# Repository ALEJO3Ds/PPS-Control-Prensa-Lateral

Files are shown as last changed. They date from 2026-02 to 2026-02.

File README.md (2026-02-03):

<h1 align="center">
  Control Mecatrónico de Prensa Lateral en Paletizadora Industrial
</h1>

<p align="center">
  <b>Práctica Profesional Supervisada – Ingeniería Mecatrónica</b><br>
  <b>Universidad Nacional de Lomas de Zamora – Facultad de Ingeniería</b>
</p>

---

## 📑 Índice
1. [Introducción](#-introducción)
2. [Objetivo](#-objetivo)
3. [Sistema intervenido](#-sistema-intervenido)
4. [Solución implementada](#-solución-implementada)
   - [Modos FULL / LIMITADO](#-modos-full--limitado)
   - [PLC – Señales y lógica](#-plc--señales-y-lógica)
   - [HMI – Selección de modo](#-hmi--selección-de-modo)
   - [Sensor IFM MR0120 – Montaje y conexión](#-sensor-ifm-mr0120--montaje-y-conexión)
   - [Consideración neumática](#-consideración-neumática)
5. [Análisis mecánico](#-análisis-mecánico)
6. [Estructura del repositorio](#-estructura-del-repositorio)
7. [Cómo abrir y utilizar los proyectos](#-cómo-abrir-y-utilizar-los-proyectos)
8. [Archivos incluidos](#-archivos-incluidos)
9. [Autor](#-autor)

---

## 📌 Introducción

Este repositorio documenta el desarrollo de una **Práctica Profesional Supervisada (PPS)** realizada sobre un equipo industrial real: una **paletizadora automática** equipada con una **prensa lateral neumática**.

La mejora consistió en incorporar un **modo de prensado limitado** configurable desde HMI mediante un **sensor magnético ON/OFF (IFM MR0120)**, manteniendo la **secuencia** y **temporizaciones originales** del ciclo.

<p align="center">
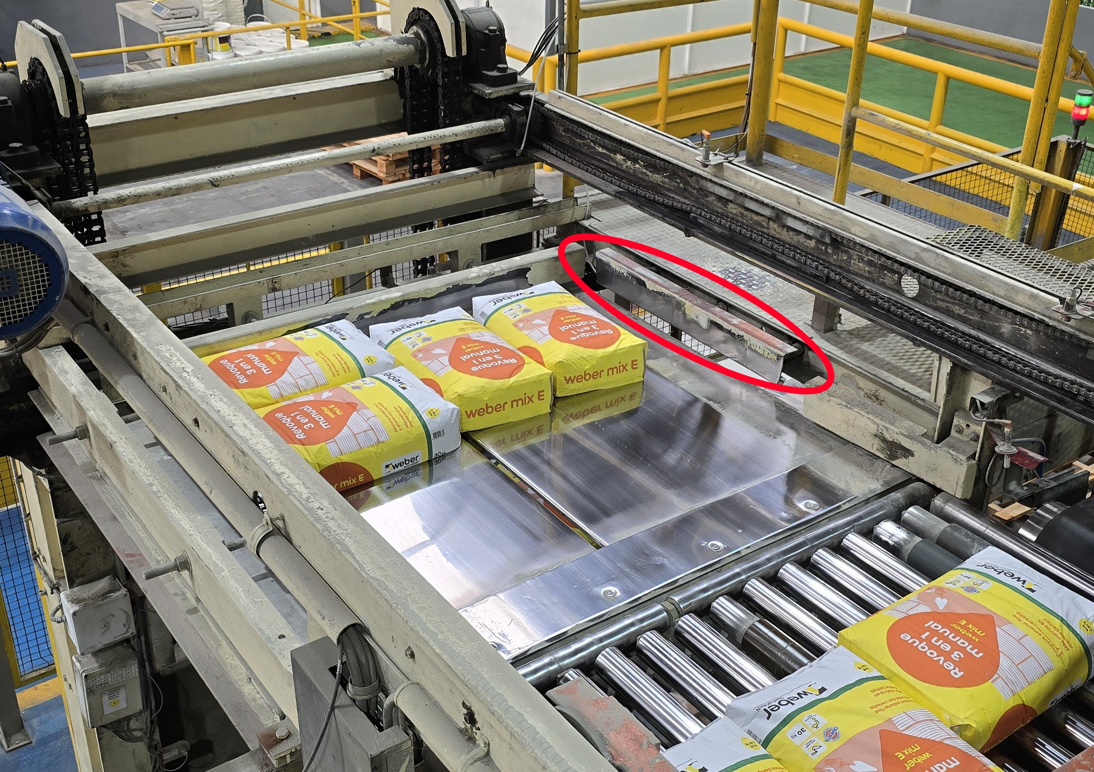
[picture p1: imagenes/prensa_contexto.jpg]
Prensa en paletizadora
  <br>
  <em>Prensa lateral neumática integrada en la paletizadora industrial</em>
</p>

---

## 🎯 Objetivo

Implementé una mejora de control para **limitar el recorrido del cilindro neumático** según necesidad operativa, sin modificar:

- la secuencia automática existente,
- las temporizaciones originales del ciclo,
- el comportamiento manual ya validado.

La solución permite detener el avance del cilindro en una posición intermedia definida por sensor, **manteniendo presión durante el tiempo original de prensado**.

---

## 🏭 Sistema intervenido

- **PLC:** Omron CJ2M-CPU34  
- **HMI:** Omron NS5  
- **Software PLC:** CX-Programmer  
- **Software HMI:** CX-Designer  
- **Cilindro neumático:** Micro 0.049.260.300 (doble efecto, con imán, carrera 300 mm)  
- **Electroválvula:** 5/3 centro cerrado  
- **Sensor agregado:** IFM MR0120 (magnético ON/OFF)

<p align="center">
  <b>Conjunto mecánico de la prensa lateral</b><br>
</p>

<table align="center">
  <tr>
    <td align="center">
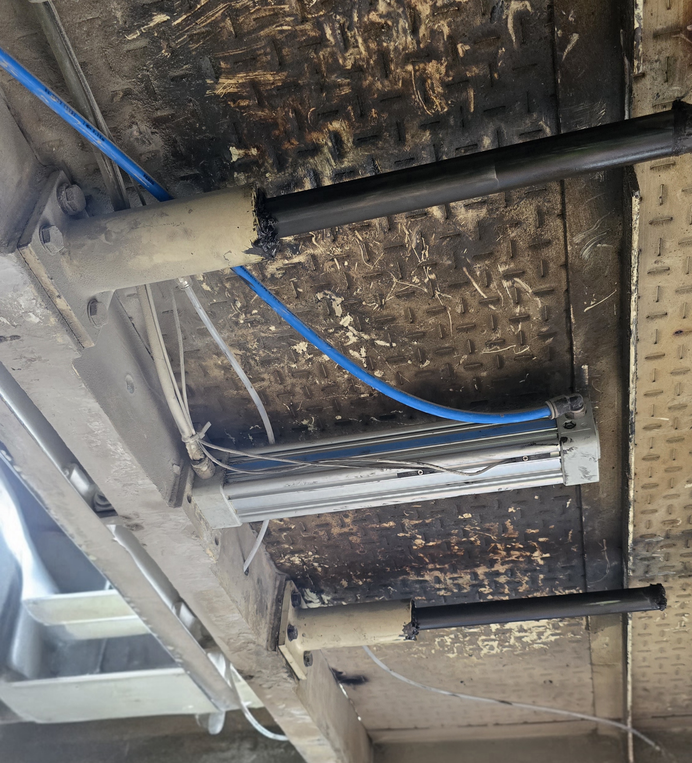
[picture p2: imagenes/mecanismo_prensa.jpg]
Implementación real de la prensa lateral
      <br>
      <em>Implementación real en paletizadora</em>
    </td>
    <td align="center">
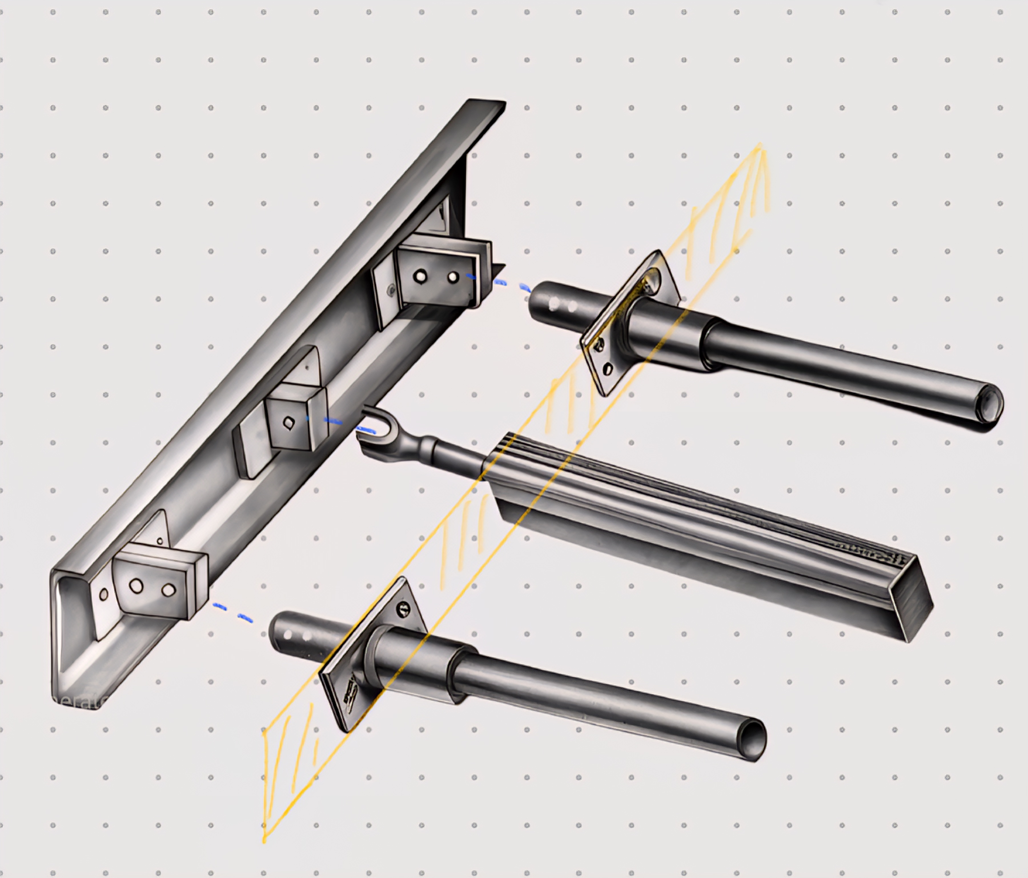
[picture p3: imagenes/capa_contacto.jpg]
Croquis del mecanismo de prensado
      <br>
      <em>Croquis / esquema mecánico</em>
    </td>
  </tr>
</table>

---

## ⚙️ Solución implementada

### 🔹 Modos FULL / LIMITADO

**Modo FULL**
- Comportamiento idéntico al original.
- El cilindro avanza a carrera completa.
- El sensor es ignorado por lógica.

**Modo LIMITADO**
- El avance se detiene cuando el sensor detecta el imán del pistón.
- Se conserva el tiempo de prensado del ciclo.
- El retroceso ocurre por la lógica global existente, sin agregar pasos nuevos.

---

### 🧠 PLC – Señales y lógica

**Entrada digital (sensor):**
- `S_PRENSA_LIMIT` → **CIO 3.14**

**Bit de modo (desde HMI):**
- `PRENSA_MODO_LIMITADO` → **CIO 610.09**
  - `0` = FULL (recorrido completo)
  - `1` = LIMITADO (recorrido limitado por sensor)

**Bit interno (bloqueo):**
- `BLOQUEO_PRENSA_LIMIT` → **W500.00**

**Cálculo del bloqueo:**
- `BLOQUEO_PRENSA_LIMIT = PRENSA_MODO_LIMITADO AND S_PRENSA_LIMIT`

**Acción sobre el avance (Y12):**
- Se agregó `NOT BLOQUEO_PRENSA_LIMIT` en los rungs que energizan el avance.
- En FULL, la lógica queda equivalente al programa original.
- En LIMITADO, al activarse el sensor se impide continuar el avance.

<p align="center">
  Rungs principales (avance/retorno)<br>
  <em>Rungs principales asociados a avance (Y12) y retroceso (Y34) de la prensa lateral en modo automático</em>
</p>

**Retroceso (Y34):**
- Se mantuvo el criterio del ciclo existente, evitando dobles mandos y conservando la secuencia validada.

---

### 🖥️ HMI – Selección de modo

La pantalla modificada fue **0011 – Programa**.  
Los Programas 1 y 2 escriben en **DM200** (selección de receta/ciclo), por lo que el modo FULL/LIMITADO se definió como **configuración global** independiente del programa activo.

Se agregaron dos botones con indicación por lámpara:

- **Prensa FULL:** escribe `0` en `HOST3:00610.09`
- **Prensa LIMITADA:** escribe `1` en `HOST3:00610.09`

<p align="center">
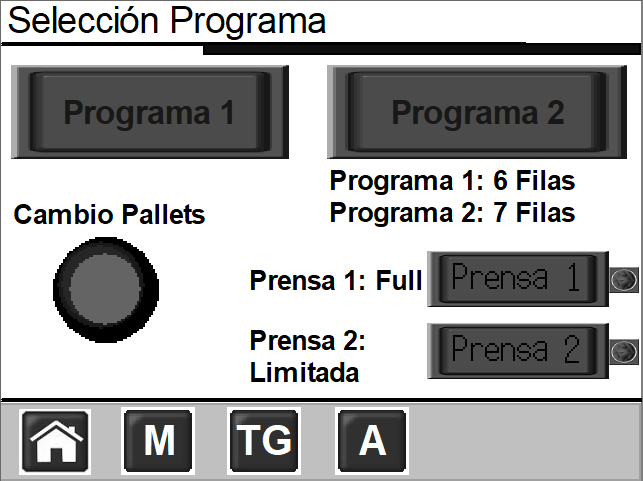
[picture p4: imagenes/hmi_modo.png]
HMI - Selección FULL/LIMITADO
  <br>
  <em>Pantalla HMI con selección de modo FULL / LIMITADO para la prensa lateral</em>
</p>

---

### 🔌 Sensor IFM MR0120 – Montaje y conexión

El sensor IFM MR0120 se monta sobre el cuerpo del cilindro y detecta el imán del pistón en una posición intermedia definida en la puesta a punto.

<p align="center">
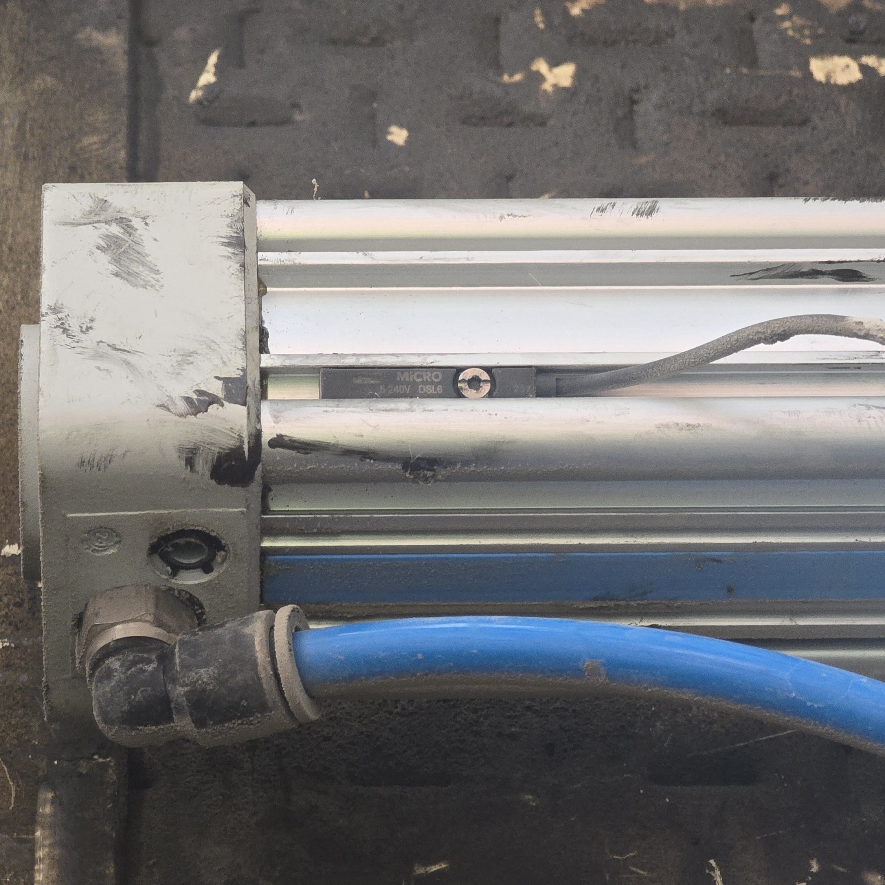
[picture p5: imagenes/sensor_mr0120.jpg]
Sensor montado en cilindro
  <br>
  <em>Sensor IFM MR0120 instalado sobre el cilindro neumático (detección magnética ON/OFF)</em>
</p>

**Conexión eléctrica (lógica PLC):**
- El sensor se cableó a la **entrada digital CIO 3.14** (`S_PRENSA_LIMIT`).

**Conexión física (dónde va el cable):**
- **PLC:** Omron CJ2M-CPU34  
- **Módulo de entradas:** **CJ1W-ID211 (DC Input Unit)**  
- **Ubicación:** Bastidor principal – **Slot 03**  
- **Borne:** **Entrada digital Nº14** del módulo (asociada a **CIO 3.14**)

> Nota: en Omron, el banco **CIO 3.xx** corresponde al módulo cuyo número de unidad/slot es **03** (16 entradas → 3.00 a 3.15).  
> Por eso **3.14** refiere a la entrada 14 de ese módulo.

**Recomendaciones de instalación:**
- Ajustar la posición del sensor según el recorrido máximo deseado.
- Verificar repetibilidad de la señal antes de habilitar el modo LIMITADO.
- Asegurar fijación mecánica firme para evitar desplazamientos por vibración.

---

### ⚠️ Consideración neumática

Se recomienda instalar una **válvula estranguladora antirretorno** para regular la velocidad del cilindro durante el avance.

**Motivo:**
- Evitar que el avance sea tan rápido que supere el punto del sensor antes de ser leído por el PLC.
- Mejorar confiabilidad de detección sin afectar el prensado.

**Ajuste recomendado:**
- Evitar estrangular en exceso (riesgo de no alcanzar el prensado a tiempo).
- Evitar estrangular de menos (riesgo de sobrepaso del punto de detección).

---

## 🧮 Análisis mecánico

Se calculó la fuerza de avance del cilindro a 6,5 bar y se verificó el conjunto mediante simulación estática (tensiones y desplazamientos).  
El análisis permitió concluir que la estructura trabaja con margen de seguridad y que el fenómeno de sobreprensado se relaciona principalmente con el recorrido impuesto y la compresibilidad del producto.

<p align="center">
  <b>Análisis por elementos finitos (FEA)</b><br>
  <em>Condiciones de contorno y resultado de deformación del conjunto bajo carga</em>
</p>

<table align="center">
  <tr>
    <td align="center">
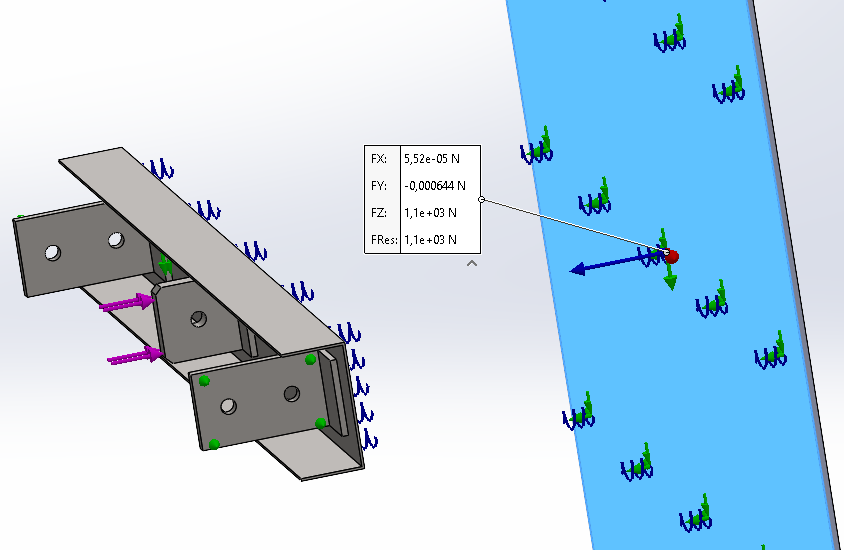
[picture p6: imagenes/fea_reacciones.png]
Configuración de cargas y reacciones (FEA)
      <br>
      <em>Configuración de cargas y reacciones</em>
    </td>
    <td align="center">
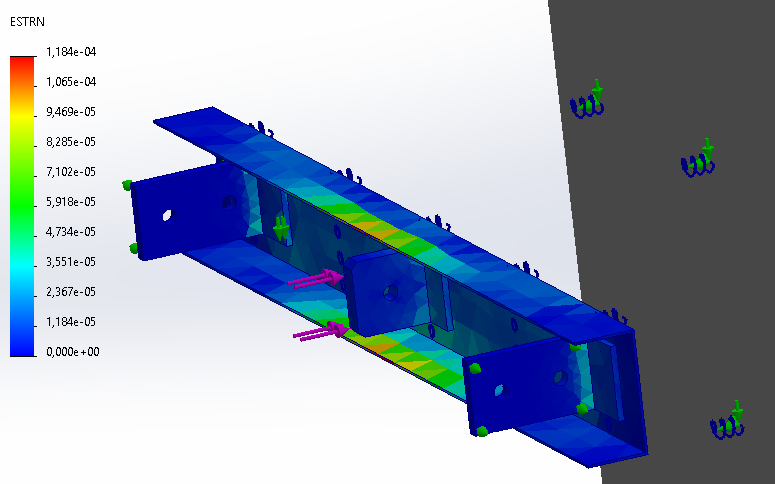
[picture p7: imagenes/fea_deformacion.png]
Resultado de deformación (FEA)
      <br>
      <em>Resultado de deformación – criterio comparativo</em>
    </td>
  </tr>
</table>

---

## 📁 Estructura del repositorio

```text
anexos/      → Documentación complementaria (PDFs)
docs/        → Informe final (PPS)
hmi/         → Proyecto HMI (.IPP) + recursos
imagenes/    → Imágenes utilizadas en este README
mecanica/    → Modelos CAD y estudios de simulación
plc/         → Proyecto PLC (.cxp) + backups y archivos asociados
```

---

## 🧰 Cómo abrir y utilizar los proyectos

### PLC (Omron CJ2M – CX-Programmer)
1. Abrí **CX-Programmer**.
2. Ir a **File → Open…** y seleccioná el archivo del proyecto:
   - `plc/PLC_Paletizadora.cxp`
3. (Opcional) Si necesitás ver el hardware configurado:
   - **PLC → I/O Table and Unit Setup** (o “Tabla de E/S” según versión).
4. Para revisar la lógica modificada:
   - Buscar las señales/símbolos:
     - `S_PRENSA_LIMIT` (CIO 3.14)
     - `PRENSA_MODO_LIMITADO` (CIO 610.09)
     - `BLOQUEO_PRENSA_LIMIT` (W500.00)
   - Ver rungs de:
     - `Y12` (EV. SALE PRENSA LATERAL)
     - `Y34` (EV. ENTRA PRENSA LATERAL)
5. Si se realiza prueba en banco/planta:
   - Conectar al PLC (USB/Serial/Ethernet según configuración del equipo).
   - **Online → Work Online**.
   - Monitorear el bit `BLOQUEO_PRENSA_LIMIT` y la entrada `CIO 3.14` al accionar el cilindro.

> ⚠️ Importante: este repositorio documenta una mejora sobre un equipo industrial real. Cualquier puesta en marcha debe respetar permisos, procedimientos internos y condiciones de seguridad del área.

---

### HMI (Omron NS5 – CX-Designer)
1. Abrí **CX-Designer**.
2. Ir a **File → Open…** y seleccioná:
   - `hmi/Pantalla_paletizadora_ver3.IPP`
3. Navegar a la pantalla modificada:
   - **Pantalla 0011 – Programa**
4. Verificar los objetos agregados:
   - Botón **Prensa FULL** → escribe `0` en `HOST3:00610.09`
   - Botón **Prensa LIMITADA** → escribe `1` en `HOST3:00610.09`
   - Lámparas asociadas al estado del bit `610.09`

---

### Sensor IFM MR0120 (montaje y conexión resumida)
- **Conexión lógica PLC:** `CIO 3.14` (`S_PRENSA_LIMIT`)
- **Conexión física (según tabla E/S):**
  - **Módulo:** `CJ1W-ID211` (DC Input Unit)
  - **Bastidor principal – Slot 03**
  - **Borne:** **Entrada digital Nº14** del módulo

> 🔧 Recomendación: ajustar una **válvula estranguladora antirretorno** para controlar la velocidad de avance del cilindro y asegurar detección confiable del sensor sin afectar el prensado.

---

## 📦 Archivos incluidos

### PLC
- `plc/PLC_Paletizadora.cxp` → Proyecto principal de PLC (Omron CX-Programmer).
- `plc/PLC_Paletizadora.bak` → Backup del proyecto.
- `plc/PLC_Paletizadora.opt` → Archivo de opciones/configuración del proyecto.
- `plc/Simbolos.pdf` → Listado de símbolos del programa PLC.
- `plc/Backup 17112025/` → Carpeta con respaldo histórico del proyecto previo a las modificaciones:
  - `PLC_Paletizadora.cxp`
  - `PLC_Paletizadora.bak`
  - `PLC_Paletizadora.cxt`
  - `PLC_Paletizadora.opt`

### HMI
- `hmi/Pantalla_paletizadora_ver3.IPP` → Proyecto HMI (Omron CX-Designer).
- `hmi/Pantalla_paletizadora_ver3/` → Carpeta asociada al proyecto HMI.
- `hmi/*.jpg` → Imágenes y recursos gráficos utilizados en la interfaz (logos, fondos, etc.).

### Mecánica
- `mecanica/Prensa.SLDASM` → Ensamble principal del conjunto de la prensa lateral.
- `mecanica/Placa.SLDPRT` → Placa estructural de la prensa.
- `mecanica/Horquilla.SLDPRT` → Horquilla del mecanismo.
- `mecanica/Orejetas.SLDPRT` → Orejetas de fijación.
- `mecanica/Prensa-EST_2_Presion_bolsas_cemento.SL3` → Estudio estático (SolidWorks Simulation).
- `mecanica/Prensa-Análisis estático 2.SL3` → Análisis estático complementario.

### Documentación
- `docs/PPS_SALTO.pdf` → Informe final de la Práctica Profesional Supervisada.
- `anexos/Funcionam-Paletizadora-Preliminar.pdf` → Descripción funcional preliminar del equipo.
- `anexos/PLC_Paletizadora_2025_General.pdf` → Documentación general del programa PLC.
- `anexos/PLC_Paletizadora_2025_Manuales.pdf` → Manuales y referencias del sistema.
- `anexos/PLC_Paletizadora_2025_Salidas_auto.pdf` → Salidas automáticas del PLC.

### Imágenes
- `imagenes/*` → Imágenes utilizadas en este README (fotografías, croquis, capturas y resultados FEA).

### Otros
- `.gitignore` → Configuración de exclusión de archivos para Git.
- `README.md` → Documentación principal del repositorio.
---

## 👤 Autor

<p align="center">
  <b>Alejo Daniel Salto</b><br>
  Ingeniería Mecatrónica – Universidad Nacional de Lomas de Zamora (FI-UNLZ)
</p>

<p align="center">
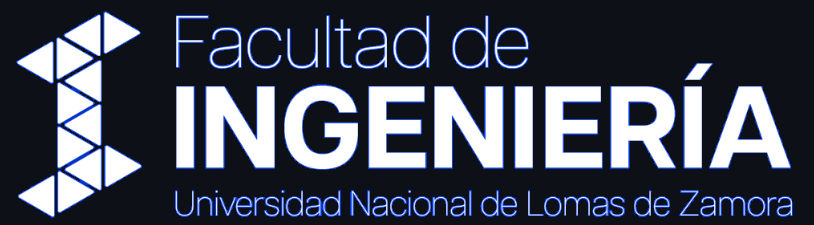
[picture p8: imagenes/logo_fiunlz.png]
Logo FiUNLZ
  
</p>

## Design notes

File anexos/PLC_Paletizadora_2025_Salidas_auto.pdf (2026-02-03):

CEMI Automatización | RDC

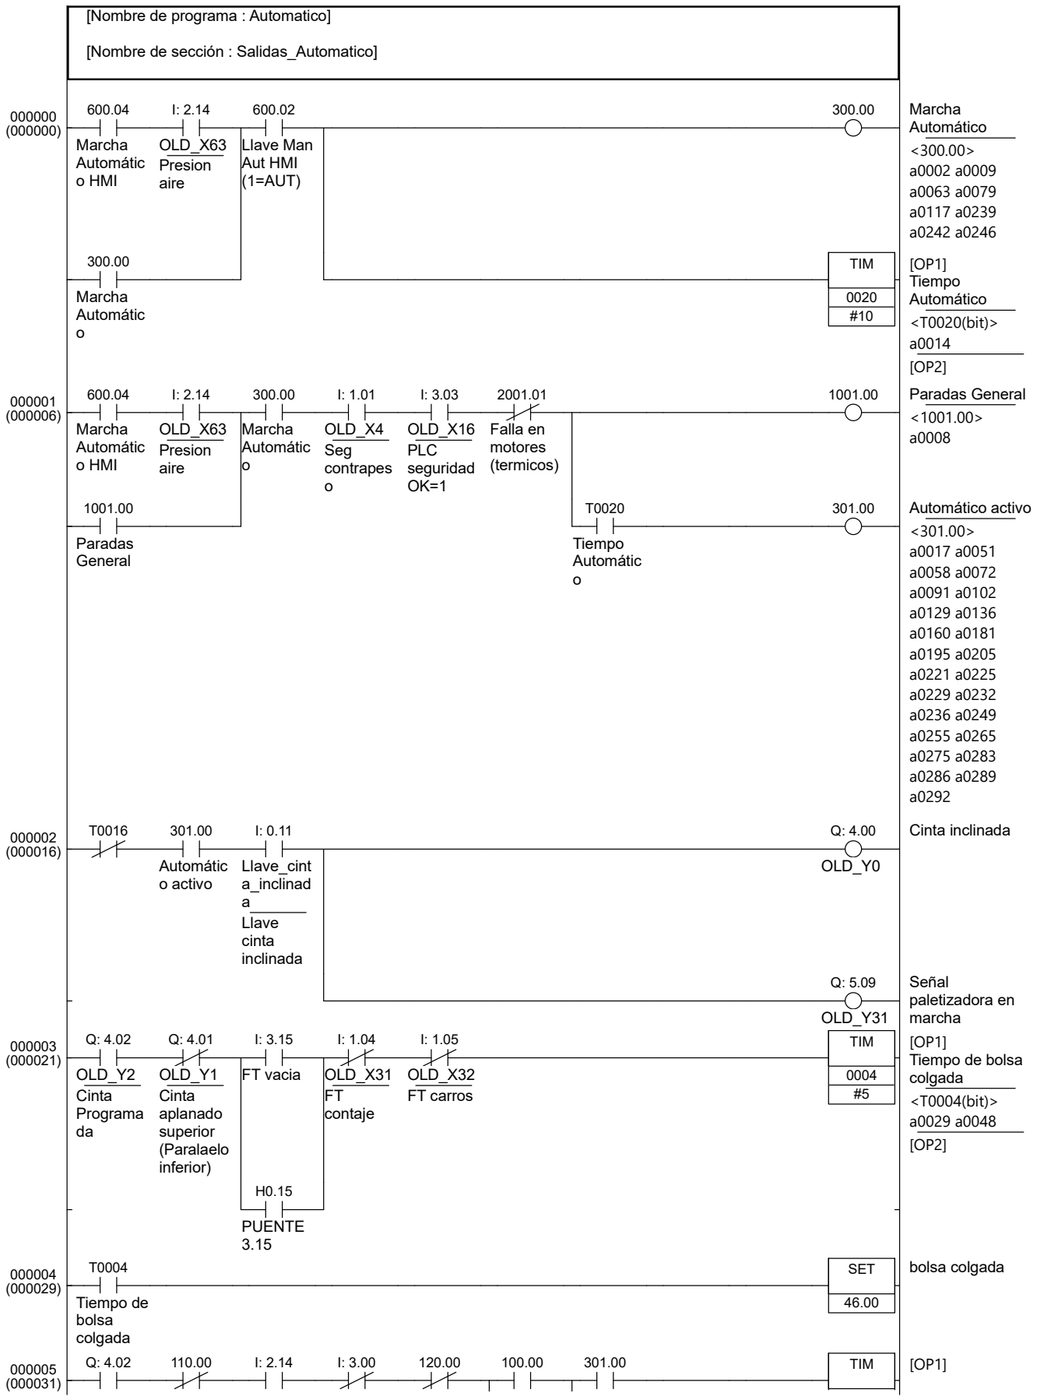
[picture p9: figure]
[Nombre de programa : Automatico]; [Nombre de sección : Salidas_Automatico]; Marcha Automátic o HMI; OLD_X63 Presion aire; Llave Man Aut HMI (1=AUT); Marcha; Automático <300.00> a0002 a0009 a0063 a0079 a0117 a0239 a0242 a0246; Marcha Automátic o; TIM; [OP1] Tiempo Automático <T0020(bit)> a0014 [OP2]; OLD_X4 Seg contrapes o; OLD_X16 PLC seguridad OK=1; Falla en motores (termicos); Paradas General; Tiempo Automátic o; Automático activo; Automátic o activo; Llave_cint a_inclinad a Llave cinta inclinada; OLD_Y0; Cinta inclinada; OLD_Y31; Señal paletizadora en marcha; OLD_Y2 Cinta Programa da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

17/11/2025 | 1 / 9 | PLC_Paletizadora.cxp

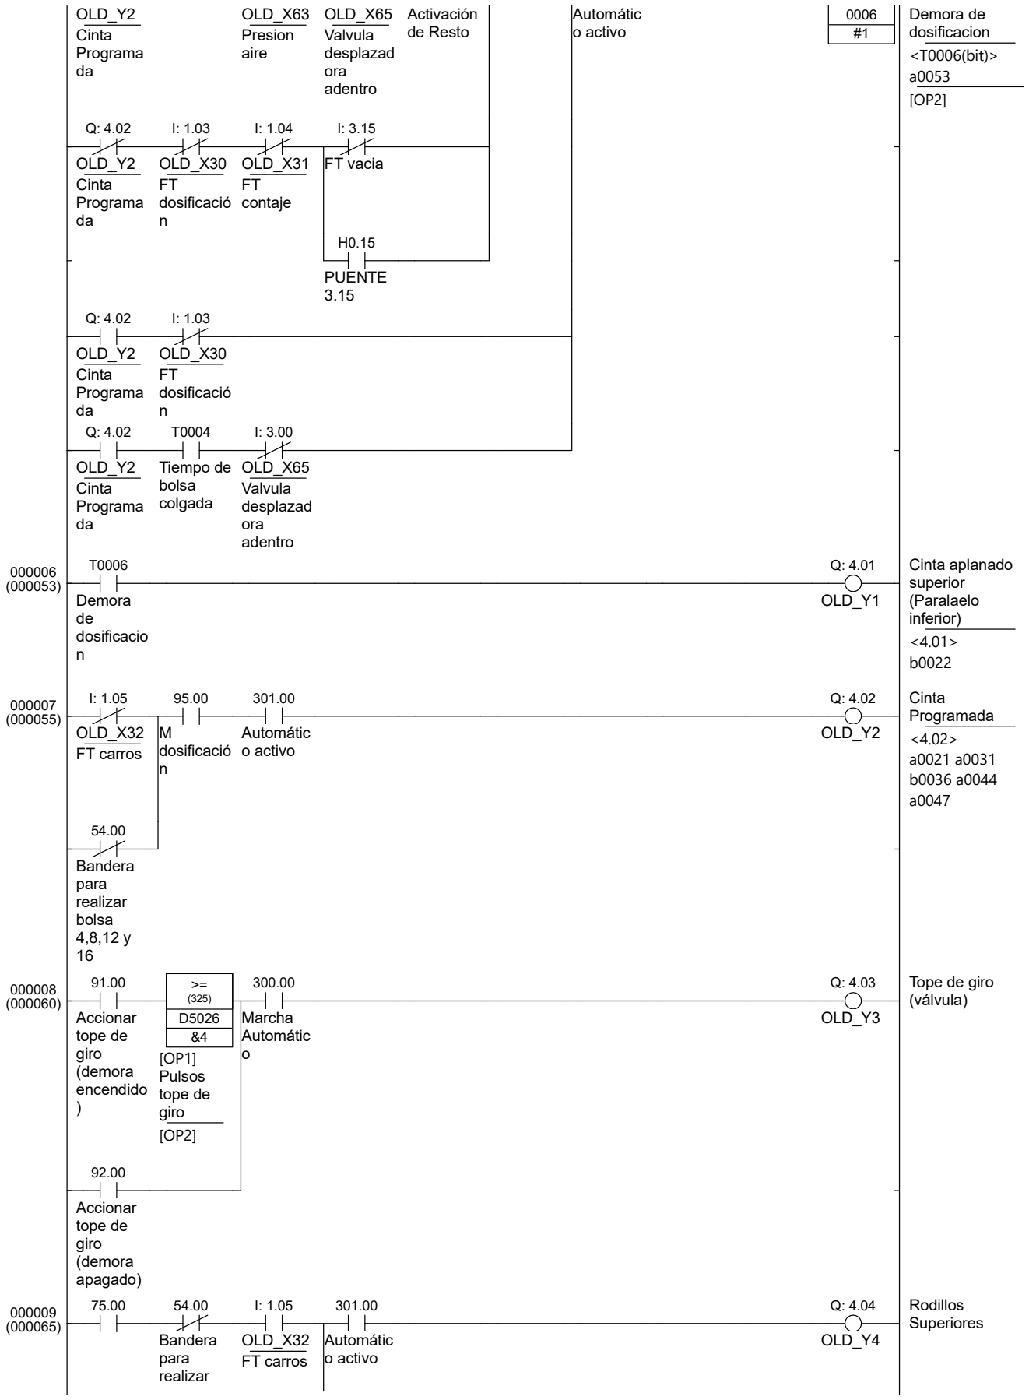
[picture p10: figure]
OLD_Y2 Cinta Programa da; OLD_X63 Presion aire; OLD_X65 Valvula desplazad ora adentro; Activación de Resto; Automátic o activo; Demora de dosificacion <T0006(bit)> a0053 [OP2]; OLD_X30 FT dosificació n; OLD_X31 FT contaje; FT vacia; PUENTE 3.15; Tiempo de bolsa colgada; Demora de dosificacio n; OLD_Y1; Cinta aplanado superior (Paralaelo inferior) <4.01> b0022; OLD_X32 FT carros; M dosificació n; OLD_Y2; Cinta Programada <4.02> a0021 a0031 b0036 a0044 a0047; Bandera para realizar bolsa 4,8,12 y 16; Accionar tope de giro (demora encendido ); >= (325) D5026 &4 [OP1] Pulsos tope de giro [OP2]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

17/11/2025 | 2 / 9 | PLC_Paletizadora.cxp

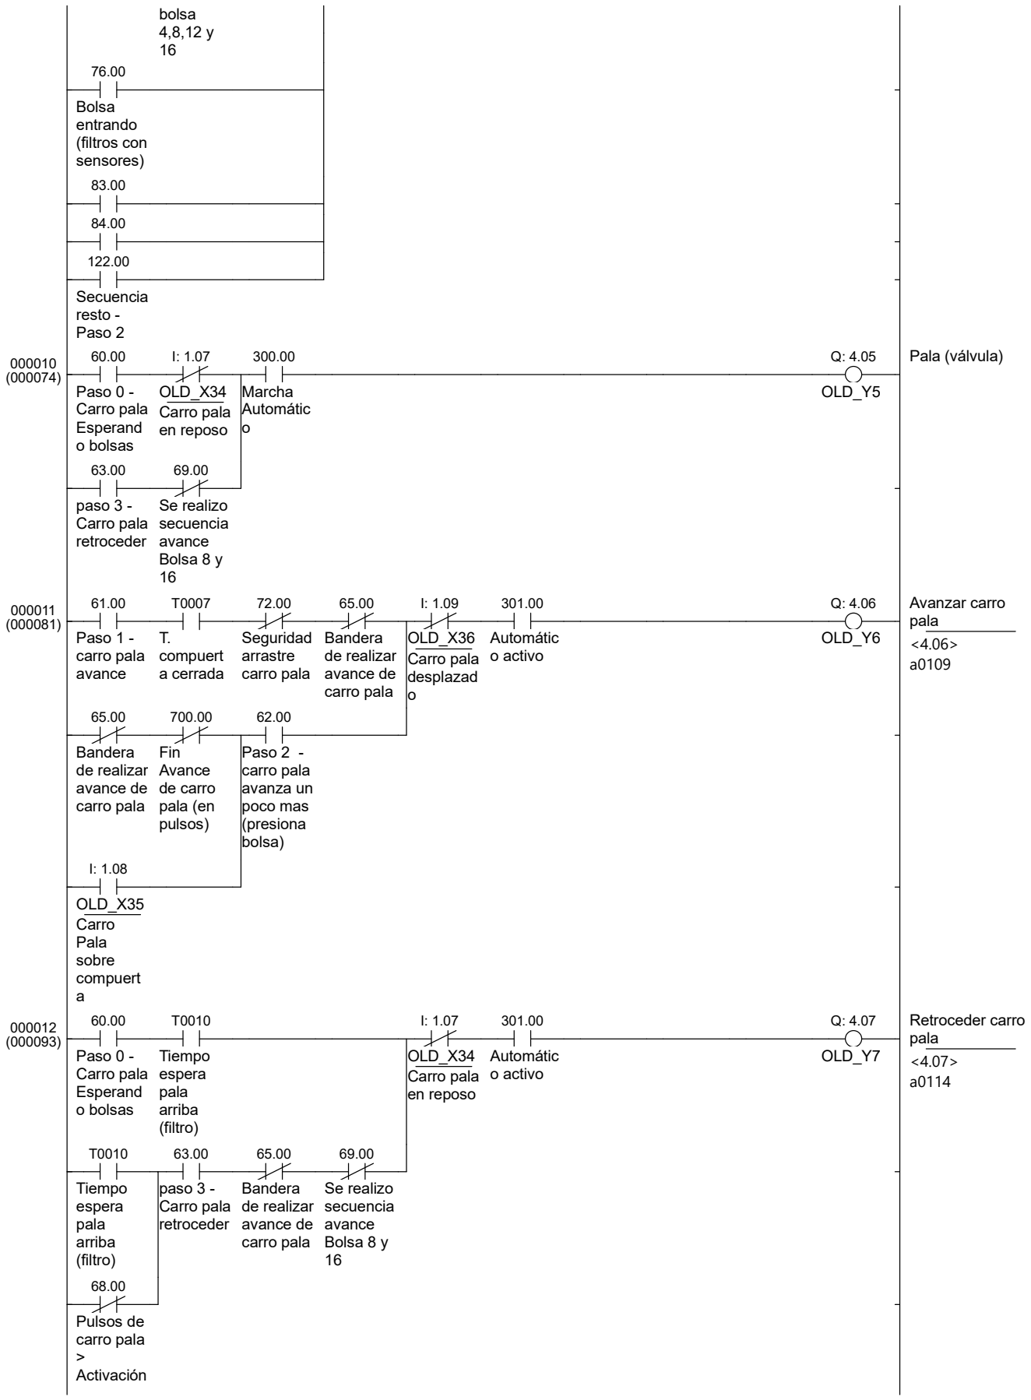
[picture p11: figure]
bolsa 4,8,12 y 16; Bolsa entrando (filtros con sensores); Secuencia resto - Paso 2; Paso 0 - Carro pala Esperand o bolsas; OLD_X34 Carro pala en reposo; Marcha Automátic o; OLD_Y5; Pala (válvula); paso 3 - Carro pala retroceder; Se realizo secuencia avance Bolsa 8 y 16; Paso 1 - carro pala avance; T. compuert a cerrada; Seguridad arrastre carro pala; Bandera de realizar avance de carro pala; OLD_X36 Carro pala desplazad o; Automátic o activo; OLD_Y6; Avanzar carro pala <4.06> a0109; Fin Avance de carro pala (en pulsos); Paso 2 - carro pala avanza un poco mas (presiona bolsa)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

17/11/2025 | 3 / 9 | PLC_Paletizadora.cxp

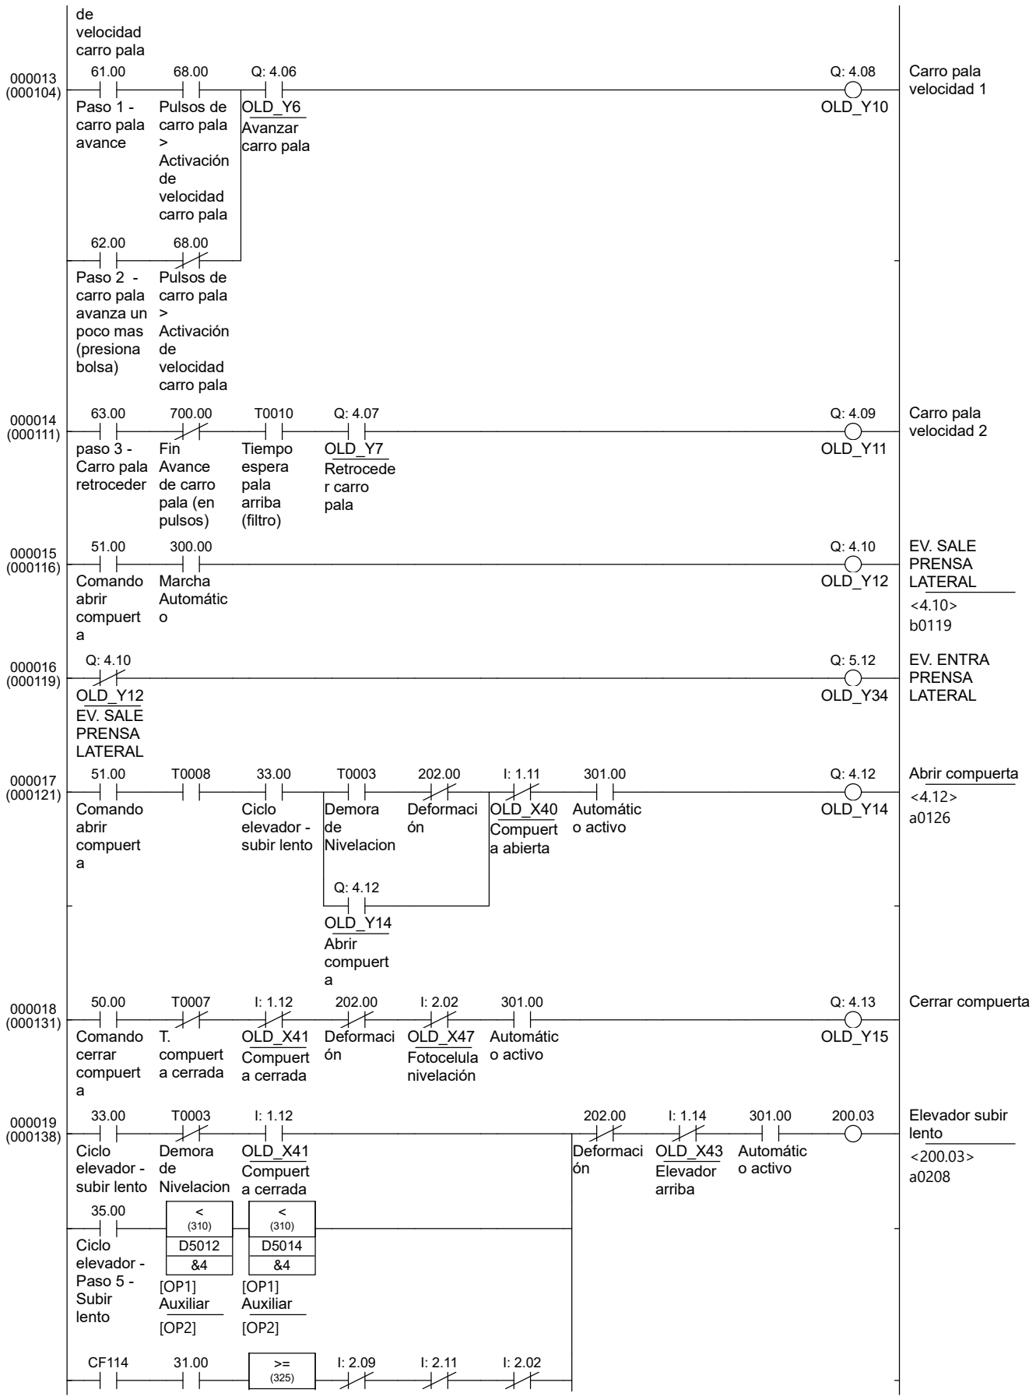
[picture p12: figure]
de velocidad carro pala; Paso 1 - carro pala avance; Pulsos de carro pala > Activación de velocidad carro pala; OLD_Y6 Avanzar carro pala; OLD_Y10; Carro pala velocidad 1; Paso 2 - carro pala avanza un poco mas (presiona bolsa); paso 3 - Carro pala retroceder; Fin Avance de carro pala (en pulsos); Tiempo espera pala arriba (filtro); OLD_Y7 Retrocede r carro pala; OLD_Y11; Carro pala velocidad 2; Comando abrir compuert a; Marcha Automátic o; OLD_Y12; EV. SALE PRENSA LATERAL <4.10> b0119; OLD_Y12 EV. SALE PRENSA LATERAL; OLD_Y34; EV. ENTRA PRENSA LATERAL; Ciclo elevador - subir lento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

17/11/2025 | 4 / 9 | PLC_Paletizadora.cxp

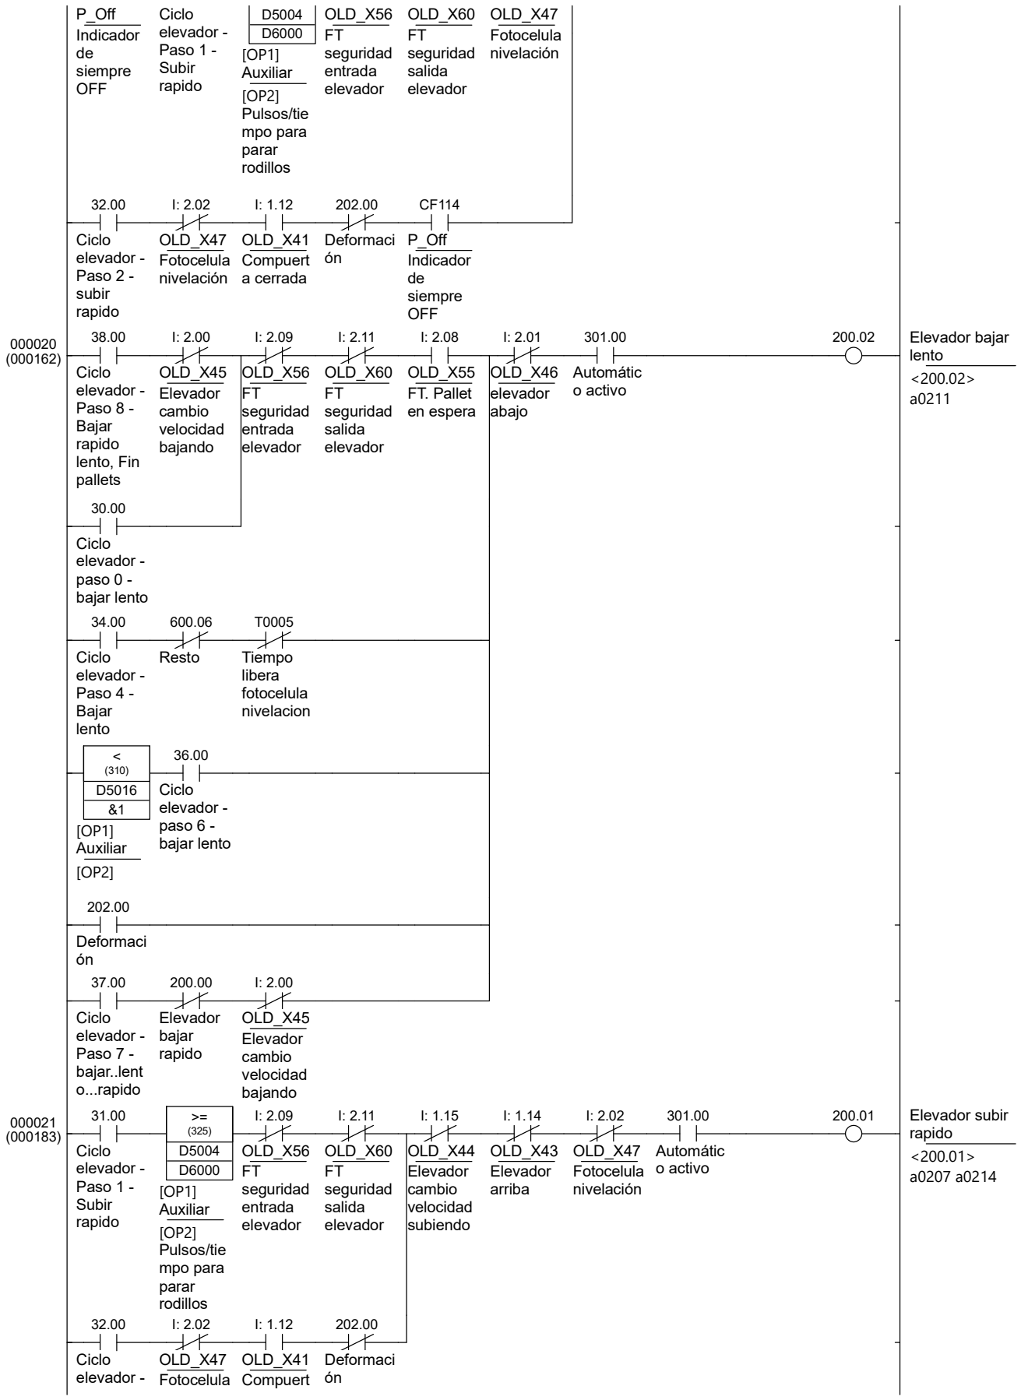
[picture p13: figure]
P_Off Indicador de siempre OFF; Ciclo elevador - Paso 1 - Subir rapido; D5004 D6000 [OP1] Auxiliar [OP2] Pulsos/tie mpo para parar rodillos; OLD_X56 FT seguridad entrada elevador; OLD_X60 FT seguridad salida elevador; OLD_X47 Fotocelula nivelación; Ciclo elevador - Paso 2 - subir rapido; OLD_X41 Compuert a cerrada; Deformaci ón; Ciclo elevador - Paso 8 - Bajar rapido lento, Fin pallets; OLD_X45 Elevador cambio velocidad bajando; OLD_X55 FT. Pallet en espera; OLD_X46 elevador abajo; Automátic o activo; Elevador bajar; lento <200.02> a0211; Ciclo elevador - paso 0 - bajar lento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

17/11/2025 | 5 / 9 | PLC_Paletizadora.cxp

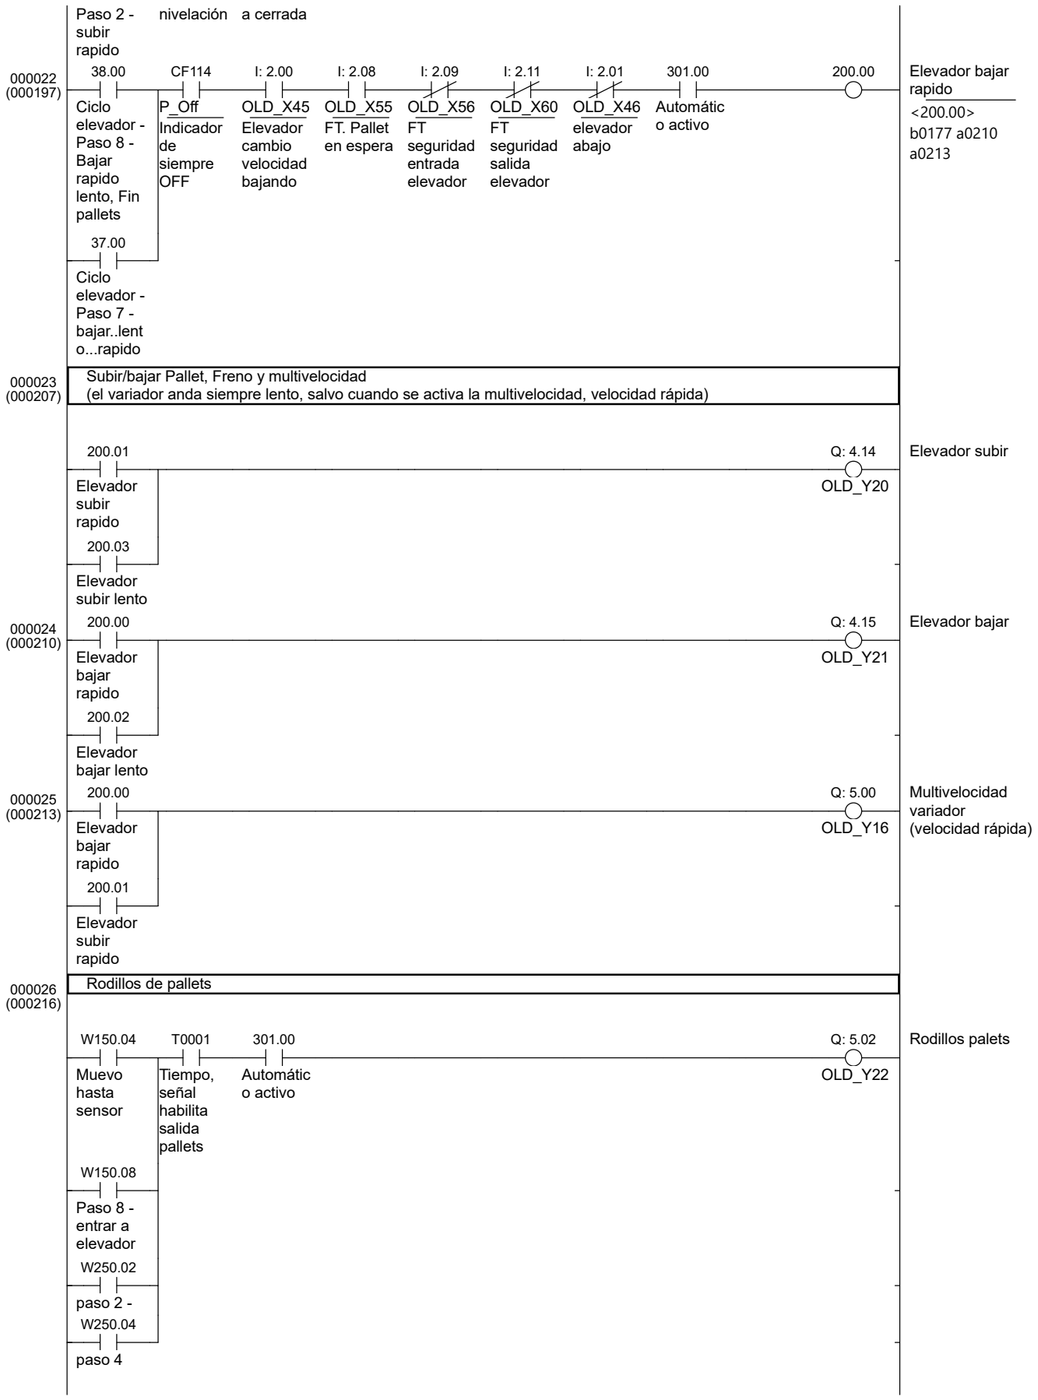
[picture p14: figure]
Paso 2 - subir rapido; nivelación a cerrada; Ciclo elevador - Paso 8 - Bajar rapido lento, Fin pallets; P_Off Indicador de siempre OFF; OLD_X45 Elevador cambio velocidad bajando; OLD_X55 FT. Pallet en espera; OLD_X56 FT seguridad entrada elevador; OLD_X60 FT seguridad salida elevador; OLD_X46 elevador abajo; Automátic o activo; Elevador bajar; rapido <200.00> b0177 a0210 a0213; Ciclo elevador - Paso 7 - bajar..lent o...rapido; Subir/bajar Pallet, Freno y multivelocidad; Elevador subir rapido; OLD_Y20; Elevador subir; Elevador subir lento; Elevador bajar rapido; OLD_Y21; Elevador bajar lento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

17/11/2025 | 6 / 9 | PLC_Paletizadora.cxp

(el variador anda siempre lento, salvo cuando se activa la multivelocidad, velocidad rápida)

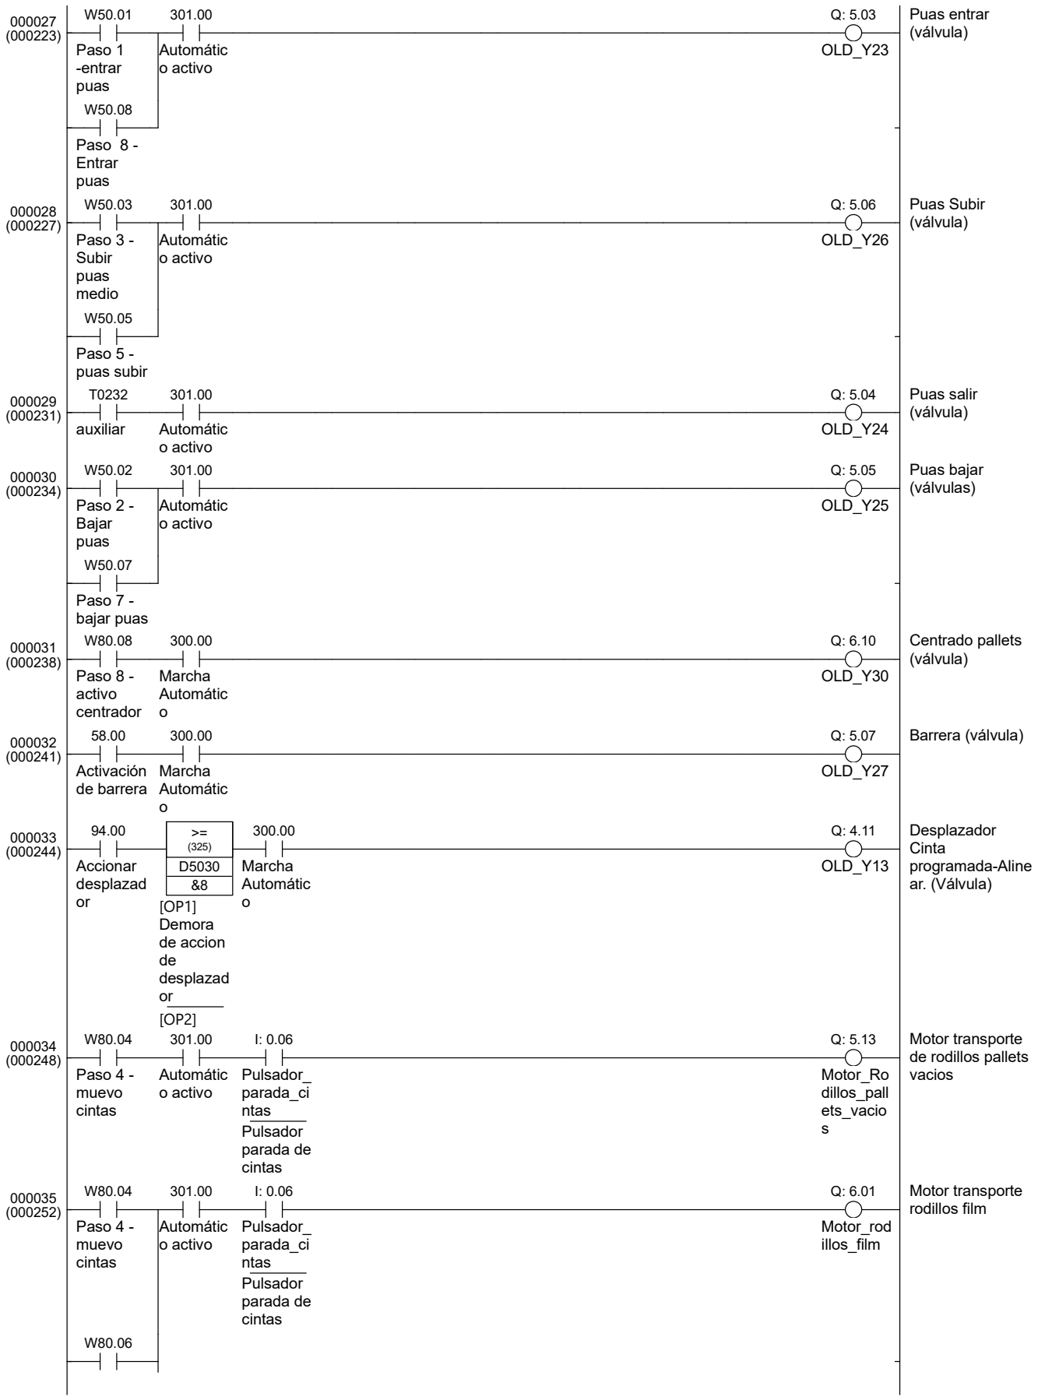
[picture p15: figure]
Paso 1 -entrar puas; Automátic o activo; OLD_Y23; Puas entrar (válvula); Paso 8 - Entrar puas; Paso 3 - Subir puas medio; OLD_Y26; Puas Subir (válvula); Paso 5 - puas subir; auxiliar; OLD_Y24; Puas salir (válvula); Paso 2 - Bajar puas; OLD_Y25; Puas bajar (válvulas); Paso 7 - bajar puas; Paso 8 - activo centrador; Marcha Automátic o; OLD_Y30; Centrado pallets (válvula); Activación de barrera; OLD_Y27; Barrera (válvula); Accionar desplazad or; >= (325) D5030 &8 [OP1] Demora de accion de desplazad or [OP2]; OLD_Y13; Desplazador Cinta programada-Alin; ar. (Válvula); Paso 4 - muevo cintas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

17/11/2025 | 7 / 9 | PLC_Paletizadora.cxp

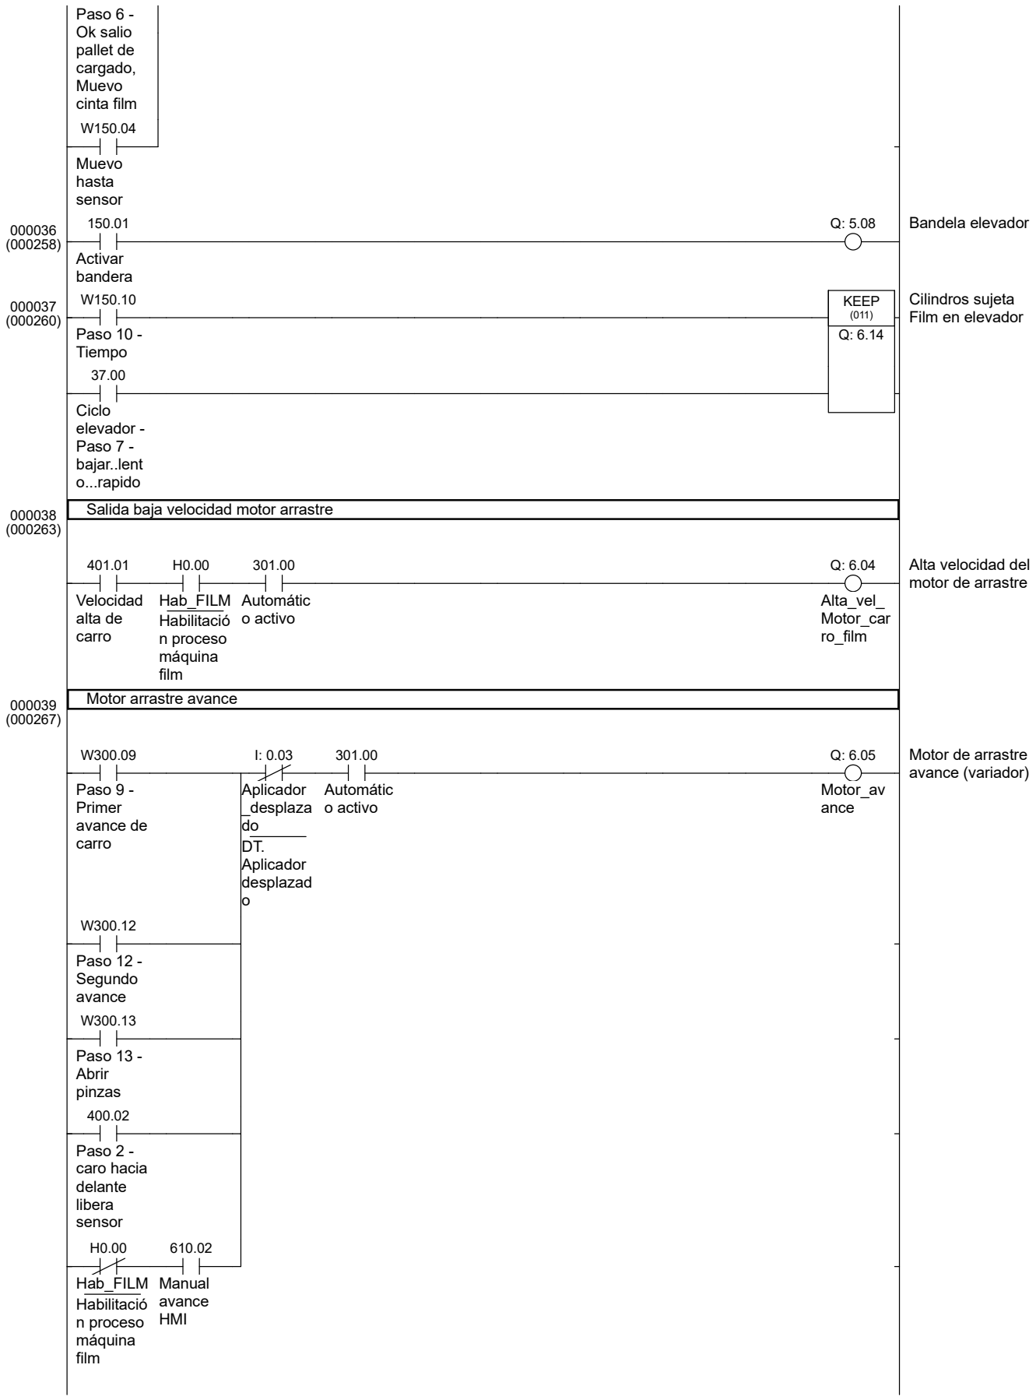
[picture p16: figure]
Paso 6 - Ok salio pallet de cargado, Muevo cinta film; Muevo hasta sensor; Activar bandera; Bandela elevador; Paso 10 - Tiempo; KEEP (011) Q: 6.14; Cilindros sujeta Film en elevador; Ciclo elevador - Paso 7 - bajar..lent o...rapido; Salida baja velocidad motor arrastre; Velocidad alta de carro; Hab_FILM Habilitació n proceso máquina film; Automátic o activo; Alta_vel_ Motor_car ro_film; Alta velocidad del motor de arrastre; Motor arrastre avance; Paso 9 - Primer avance de carro; Aplicador _desplaza do DT. Aplicador desplazad o; Motor_av ance; Motor de arrastre avance (variador)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

17/11/2025 | 8 / 9 | PLC_Paletizadora.cxp

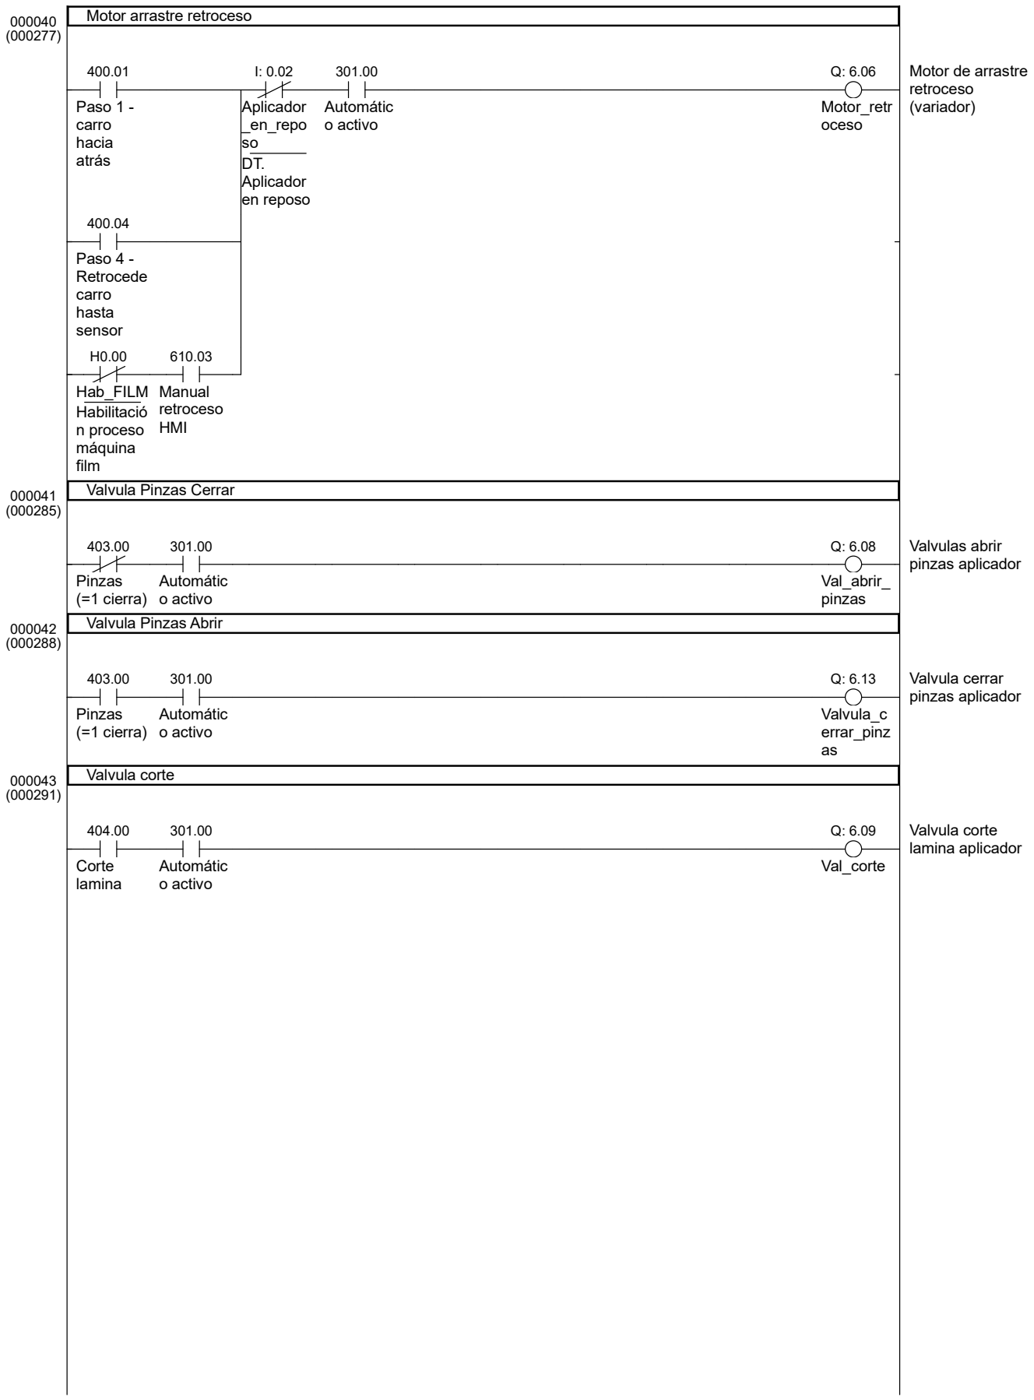
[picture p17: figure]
Motor arrastre retroceso; Paso 1 - carro hacia atrás; Aplicador _en_repo so DT. Aplicador en reposo; Automátic o activo; Motor_retr oceso; Motor de arrastre retroceso (variador); Paso 4 - Retrocede carro hasta sensor; Hab_FILM Habilitació n proceso máquina film; Manual retroceso HMI; Valvula Pinzas Cerrar; Pinzas (=1 cierra); Val_abrir_ pinzas; Valvulas abrir pinzas aplicador; Valvula Pinzas Abrir; Valvula_c errar_pinz as; Valvula cerrar pinzas aplicador; Valvula corte; Corte lamina; Val_corte; Valvula corte lamina aplicador

17/11/2025 | 9 / 9 | PLC_Paletizadora.cxp

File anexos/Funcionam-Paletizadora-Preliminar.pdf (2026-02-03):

## APARTADO nº 4

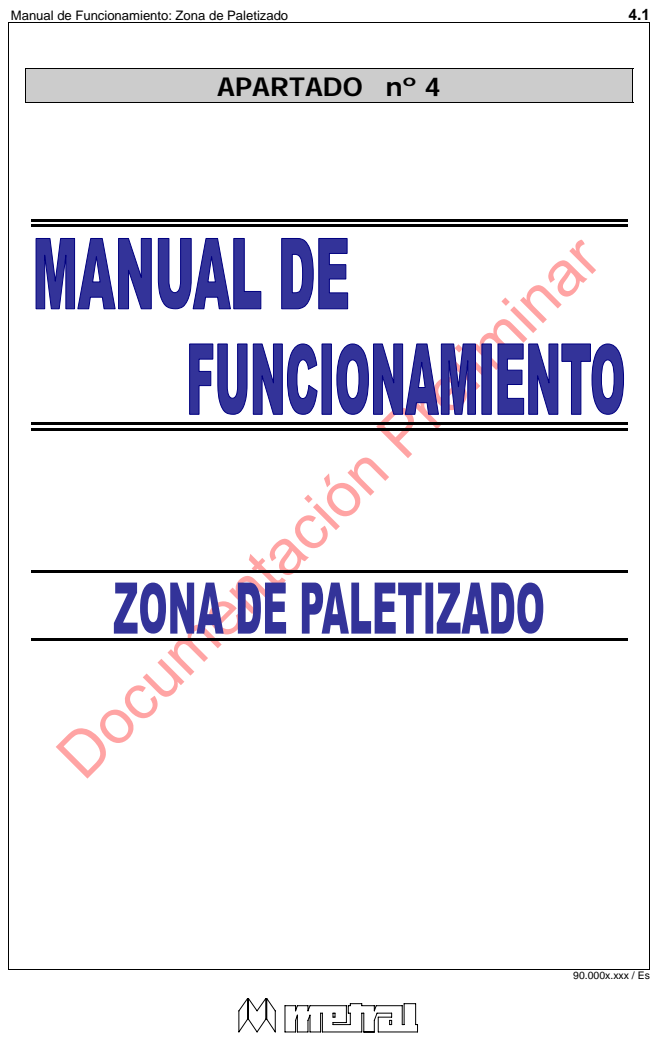
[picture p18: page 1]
Documentación Preliminar; Manual de Funcionamiento: Zona de Paletizado; 90.000x.xxx / Es

# Documentación Preliminar

### ÍNDICE

Contenido | Página

### 1. DESCRIPCIÓN PANEL DE CONTROL PALETIZADO | 4.3

### 2. FUENTES DE ALIMENTACIÓN | 4.6

### 3. FUNCIONAMIENTO EN AUTOMÁTICO | 4.7

### 3.1 PANTALLA PRINCIPAL | 4.8

### 3.2 DESCRIPCIÓN DE LOS BOTONES | 4.10

### 3.3 SEÑALES | 4.11

### 3.4 CONFIGURACIÓN: | 4.20

### 3.5 PASSWORD: | 4.24

### 3.6 AJUSTES | 4.25

### 3.7 PRODUCCIÓN | 4.45

### 4. MENU AYUDA: | 4.47

### 5. MODO DE FUNCIONAMIENTO SEMIAUTOMÁTICO | 4.48

### 6. MODO DE FUNCIONAMIENTO MANUAL | 4.51

### 7. FUNCIONES ESPECIALES | 4.53

### 7.1 RESTO (PULSADOR AMARILLO DEL CUADRO DE MANDO) | 4.53

### 7.2 PUESTA A CERO (PULSADOR AZUL DEL CUADRO DE MANDO) | 4.54

### 8. FUNCIONES DE SEGURIDAD | 4.55

### 9. AVERÍAS, ALARMAS Y FALLOS | 4.57

### 10. INSTALACIÓN DE SEGURIDAD | 4.59

## 1. DESCRIPCIÓN PANEL DE CONTROL PALETIZADO

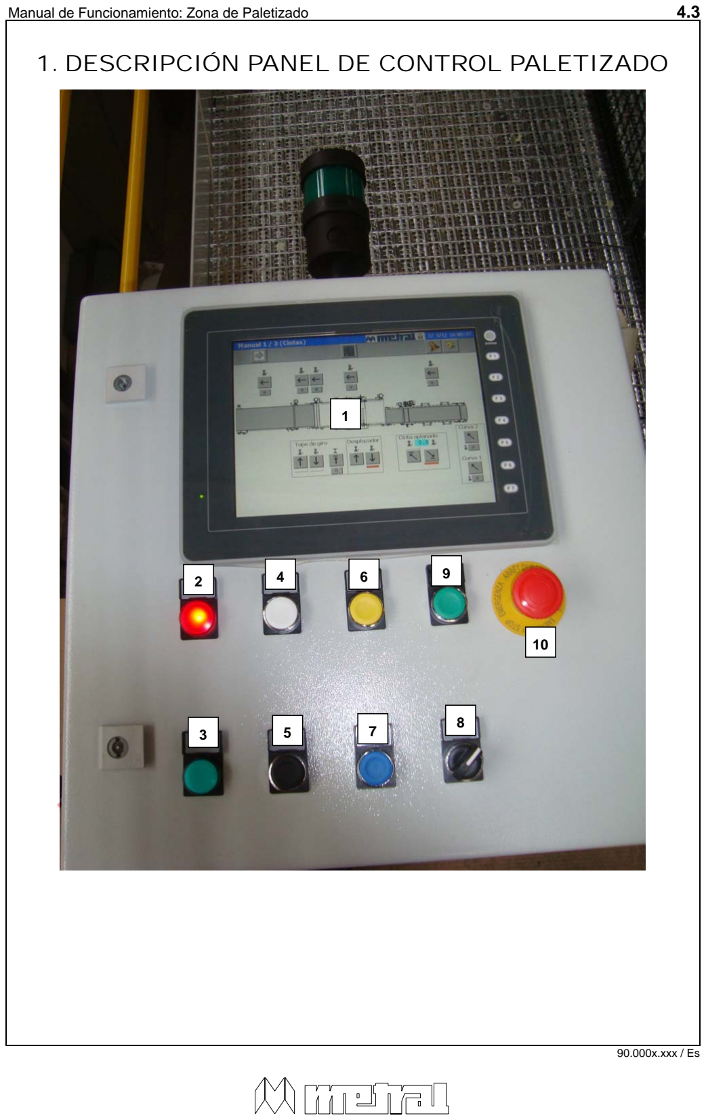
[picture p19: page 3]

# Documentación Preliminar

1

4 6

5 8 7

9

10

2

3

# Documentación Preliminar

### 1. Terminal Operador

El terminal operador es el que permitirá la comunicación entre el usuario y la instalación de paletizado.

### 2. Paletizador en Marcha (Luz de color verde)

Este piloto está iluminado cuando tenemos la seta de Paro máquina desenclavada y todas las seguridades de la línea están funcionando.

### 3. Paletizador Parado (Luz de color rojo)

Nos indica que la instalación está parada, por estar caído el módulo de seguridad.

### 4. Marcha (Pulsador de color blanco)

Automático: Este pulsador sirve para poner en funcionamiento toda la línea de paletizado si se cumplen todas las condiciones previas. Estas condiciones están indicadas en la descripción del funcionamiento automático de la instalación.
Manual: En manual, podemos seleccionar a través del terminal de operador qué elementos queremos activar para realizar el mantenimiento o determinados ajustes. Este pulsador es el que se utiliza para ponerlos en marcha. Es un pulsador sensitivo, es decir, mientras lo mantengamos pulsado los elementos activados se podrán en marcha y en el momento en que lo soltamos estos se paran.

### 5. Paro Paletizador (Pulsador negro)

Automático: Realiza un paro del ciclo que la máquina esté realizando. El ciclo en automático se mantiene parado en el estado de espera donde se estaba ejecutando. Si se pulsa marcha a continuación del ciclo en automático continua. Con este paro provocamos la pérdida de tensión de los motores, pero ésta se mantiene en los variadores. También se mantiene el aire comprimido en los cilindros neumáticos.

# Documentación Preliminar

### 6. Resto (Pulsador de color amarillo)

Nos permite hacer un resto de la producción. Detiene la entrada de sacos hacia la dosificación y sólo paletiza los que restan en la banda programada, en la zona de los rodillos superiores y encima de la compuerta.

### 7. Cero (Pulsador de color azul)

Realiza un borrado de todos los registros, contadores y memorias internas existente en el autómata, para poner la máquina en las mismas condiciones que al inicio de su funcionamiento.

### 8. Manual / Automático / Semiautomático Paletizador (selector tres

posiciones)
Selector para escoger con qué modo de funcionamiento se quiere trabajar (manual, automático o semiautomático).

### 9. Rearme Paletizador (Pulsador verde)

Cuando se ha producido una parada de emergencia o se ha abierto alguna de las puertas de seguridad, el módulo que controla las seguridades que se encuentra en el armario eléctrico, hace caer cualquier tipo de energía. Para poder poner en marcha la línea se tiene que apretar sobre este pulsador verde y luego pulsar marcha. Este rearme no provoca un arranque de la instalación, sólo autoriza a realizarlo.

### 10. Parada de emergencia zona paletizador (Seta de color rojo)

Provoca una parada de cualquier tipo de energía en la instalación de paletizado. Supone una parada brusca de la línea, por lo que tiene que considerarse un paro poco habitual. Este tipo de paro tiene prioridad sobre cualquier otra función.

# Documentación Preliminar

## 2. FUENTES DE ALIMENTACIÓN

Antes de la puesta en funcionamiento la instalación de paletizado deben activarse todas sus fuentes de alimentación de energía:

- Alimentación eléctrica
Conectar el seccionador general del cuadro eléctrico. A partir de ese momento deberá iluminarse el piloto blanco TENSIÓN del armario eléctrico, indicando que hay tensión de energía eléctrica.
Una única toma eléctrica alimenta los circuitos de potencia y los circuitos de mando.
- Alimentación de aire comprimido
Comprobar que todas las unidades de acondicionamiento de aire comprimido están correctamente alimentadas con aire a una presión superior a 6 Kg/cm²

MUY IMPORTANTE

En ningún caso deben hacerse manipulaciones en la máquina sin tener desconectadas todas las fuentes de alimentación eléctrica de la máquina.

NUNCA DESACTIVAR, SUPRIMIR O MANIPULAR LOS DISPOSITIVOS DE SEGURIDAD

No rearrancar la máquina hasta conocer el motivo del paro de emergencia.

Comprobar que ninguna persona se encuentre dentro de la zona restringida antes de desbloquear el paro y activar otra vez el proceso productivo.

# Documentación Preliminar

## 3. FUNCIONAMIENTO EN AUTOMÁTICO

El paletizador tiene dos modos de funcionamiento: automático y manual. A continuación describimos el modo de funcionamiento en automático.

El modo de funcionamiento automático es el normal de la máquina, y el único que sirve para cumplir el proceso productivo para el cual ha sido diseñada.
Para que el paletizador se ponga en marcha en modo automático se deben de cumplir las siguientes condiciones:
1. Tensión eléctrica de alimentación en la máquina.
2. Presión de aire comprimido.
3. El autómata en RUN.
4. Asegurarse de que las fotocélulas de seguridad están OK.
5. Asegurarse de que no está enclavado la PARADA DE EMERGENCIA.
6. Asegurarse de que todas las puertas de seguridad están cerradas.
7. Rearmar el Módulo de Seguridad (pulsador verde)
8. Selector en la posición de AUTOMÁTICO.

Si estas condiciones se cumplen, al pulsar MARCHA la máquina arrancará. Primero se activarán los pistones y con una ligera demora se pondrán en marcha los motores que correspondan.
La máquina puede estar en marcha con todos los elementos en reposo y ponerse en movimiento en cuanto se detecte la presencia de un saco. Al arrancar la línea suena la bocina de aviso.

# Documentación Preliminar

### 3.1 PANTALLA PRINCIPAL

Cuando pongamos la instalación en funcionamiento la primera pantalla que aparecerá es la siguiente:

Aparecen las posibles alarmas que se producen en la máquina. Pulsando encima de se accede al informe detallado de dichas alarmas.

Se visualiza el número de capas del palet actual en el elevador.

Sacos / Minuto: En este contador se pueden visualizar la cantidad de sacos producidos por minuto.

Sacos / Hora: En este contador se pueden visualizar la cantidad de sacos producidos por hora.

1

2

1

2

# Documentación Preliminar

| Programa Actual: Nos indica qué programa está ejecutando el paletizador dentro de todos los posibles.
| Contador Sacos: Número de sacos que han pasado por la zona de dosificación (saliendo de las cintas de aplanado y entrando en la banda programada). Se utiliza para ordenar el giro o desplazamiento del saco, según el mosaico. Y toda la información para configurar el mosaico.
| Contador Capas: Nos indica el número de capas que se han completado y el número total de capas que forman el palet.

# Documentación Preliminar

### 3.2 DESCRIPCIÓN DE LOS BOTONES

En las diferentes pantallas del terminal operador podrá ver los siguientes botónes.
A continuación podrá ver los botones con una descripción de su función.

Este botón activa o desactiva la entrada de sacos a la banda programada. De este modo podrá detener la producción de palets.

Señales: Mediante este botón podrá acceder a la pantalla de visualización de todas las señales.

Configuración: Mediante este botón podrá acceder a la pantalla de configuraciones de la maquina.

Password: Mediante este botón podrá acceder a la pantalla de entrada de password de la maquina.

Producción: Mediante este botón podrá acceder a la pantalla de producción.

Alarmas: Mediante este botón podrá acceder a la pantalla de visualización de las alarmas.

Ayuda: Pulsando este botón podrán ver una descripción detallada de los botones de las pantallas.

Principal: Este botón les permitirá retroceder a la pantalla principal (Solo es visible en determinadas pantallas)

Ajustes: Este botón les permitirá acceder a las pantallas de ajuste de la instalación.

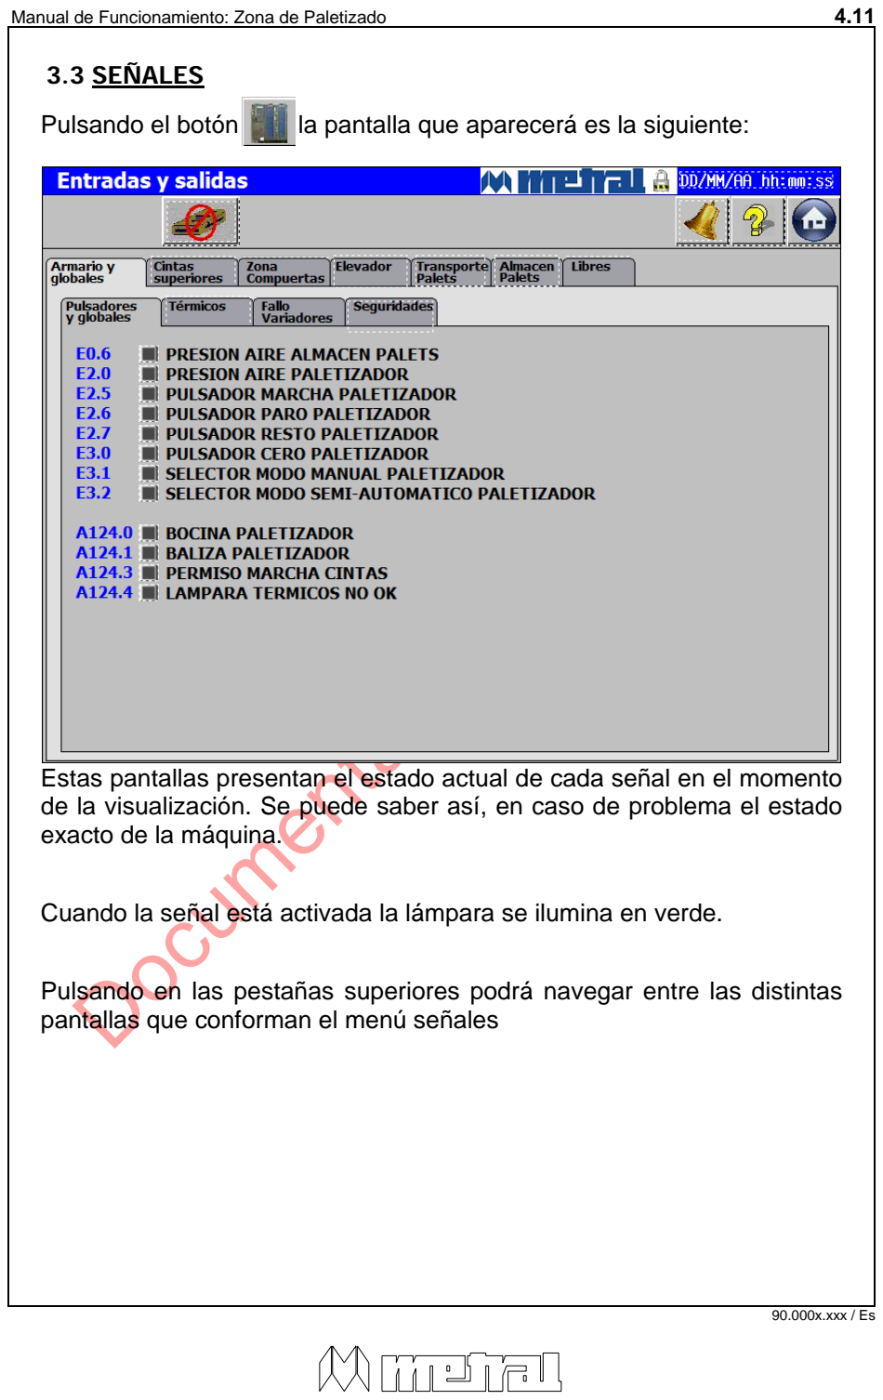
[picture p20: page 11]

# Documentación Preliminar

### 3.3 SEÑALES

Pulsando el botón la pantalla que aparecerá es la siguiente:

Estas pantallas presentan el estado actual de cada señal en el momento de la visualización. Se puede saber así, en caso de problema el estado exacto de la máquina.

Cuando la señal está activada la lámpara se ilumina en verde.

Pulsando en las pestañas superiores podrá navegar entre las distintas pantallas que conforman el menú señales

# Documentación Preliminar

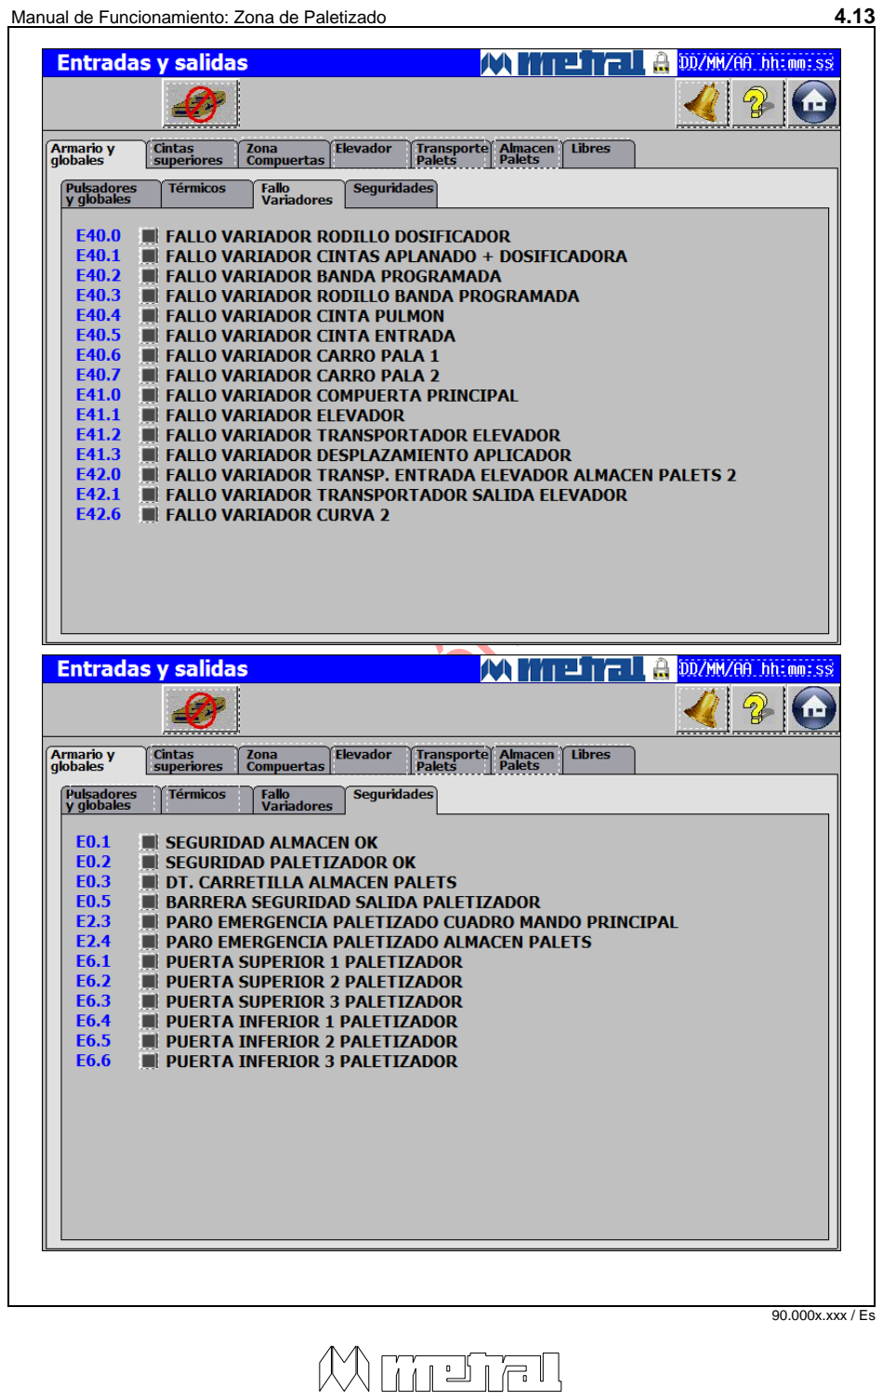
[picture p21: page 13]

# Documentación Preliminar

# Documentación Preliminar

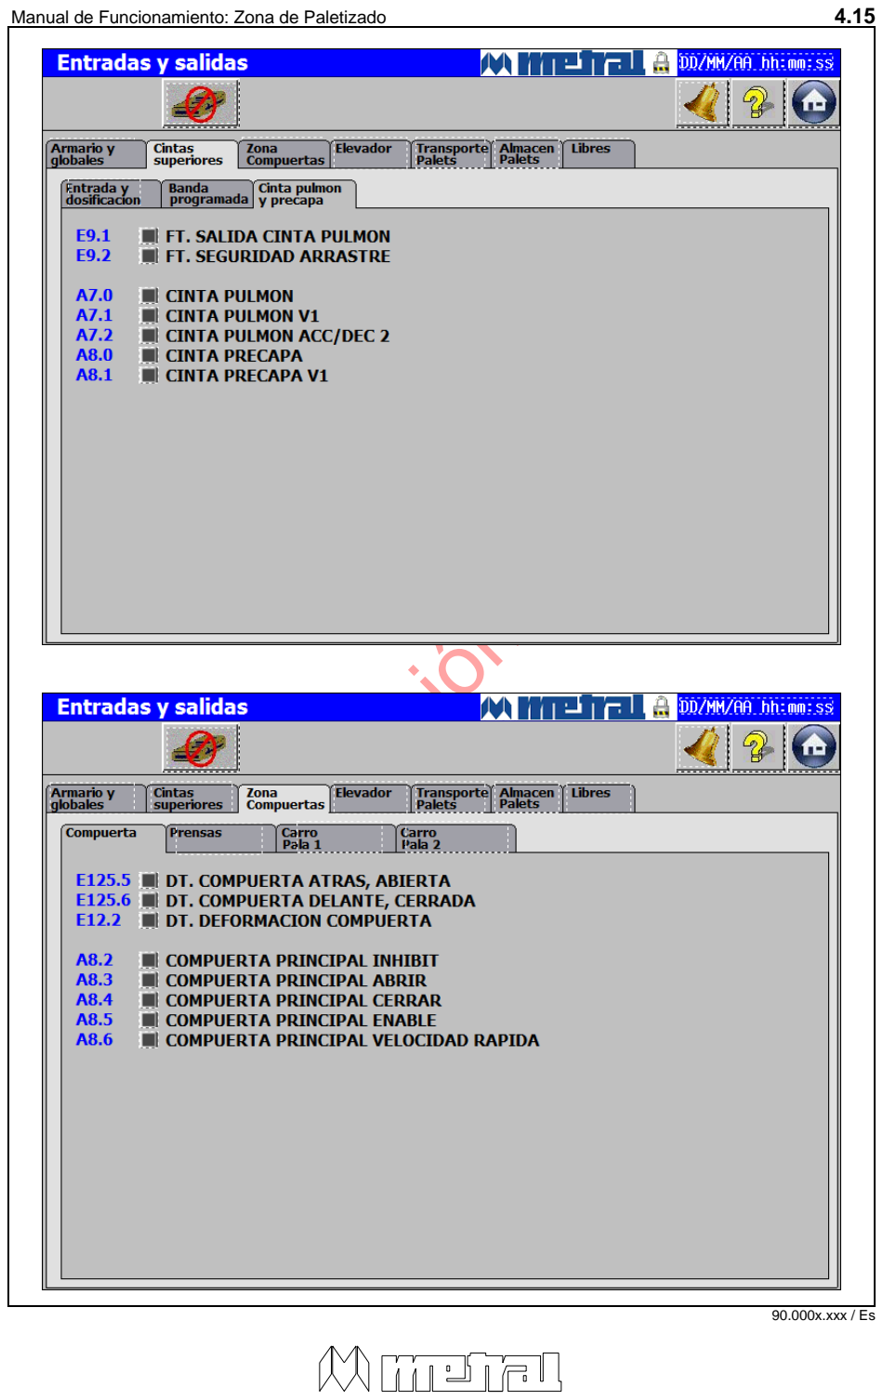
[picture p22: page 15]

# Documentación Preliminar

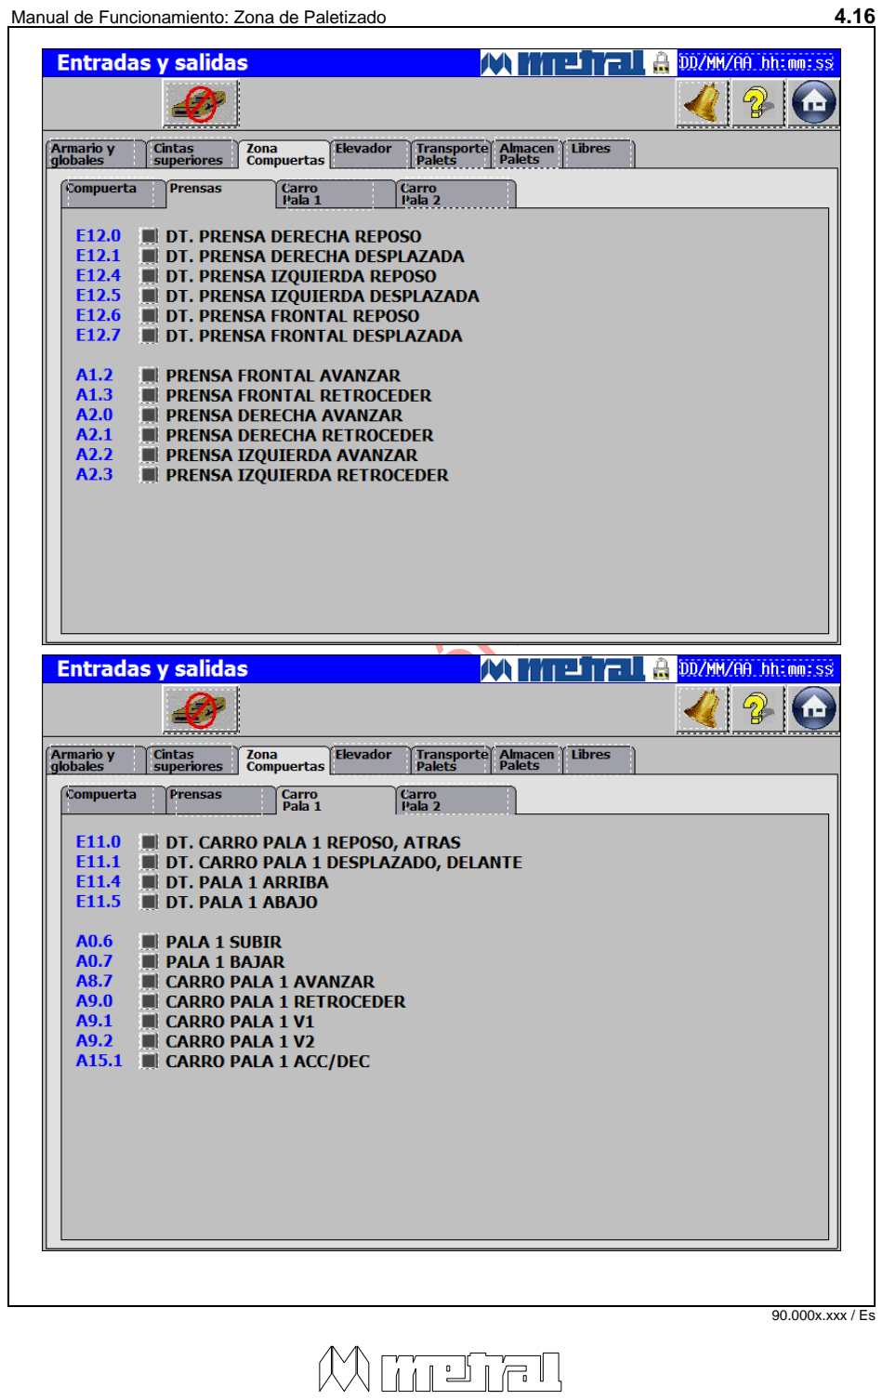
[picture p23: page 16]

# Documentación Preliminar

# Documentación Preliminar

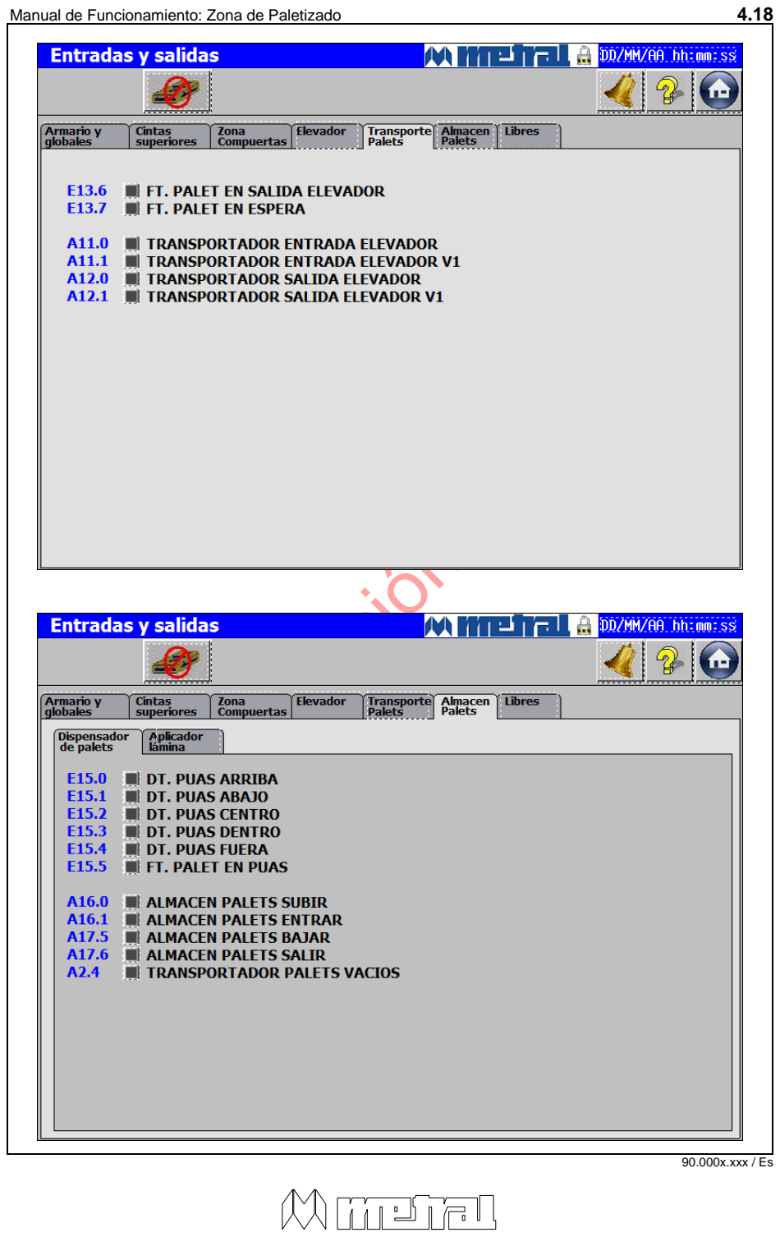
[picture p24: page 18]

# Documentación Preliminar

# Documentación Preliminar

### 3.4 CONFIGURACIÓN:

Pulsando sobre el botón la pantalla que aparece es la siguiente:

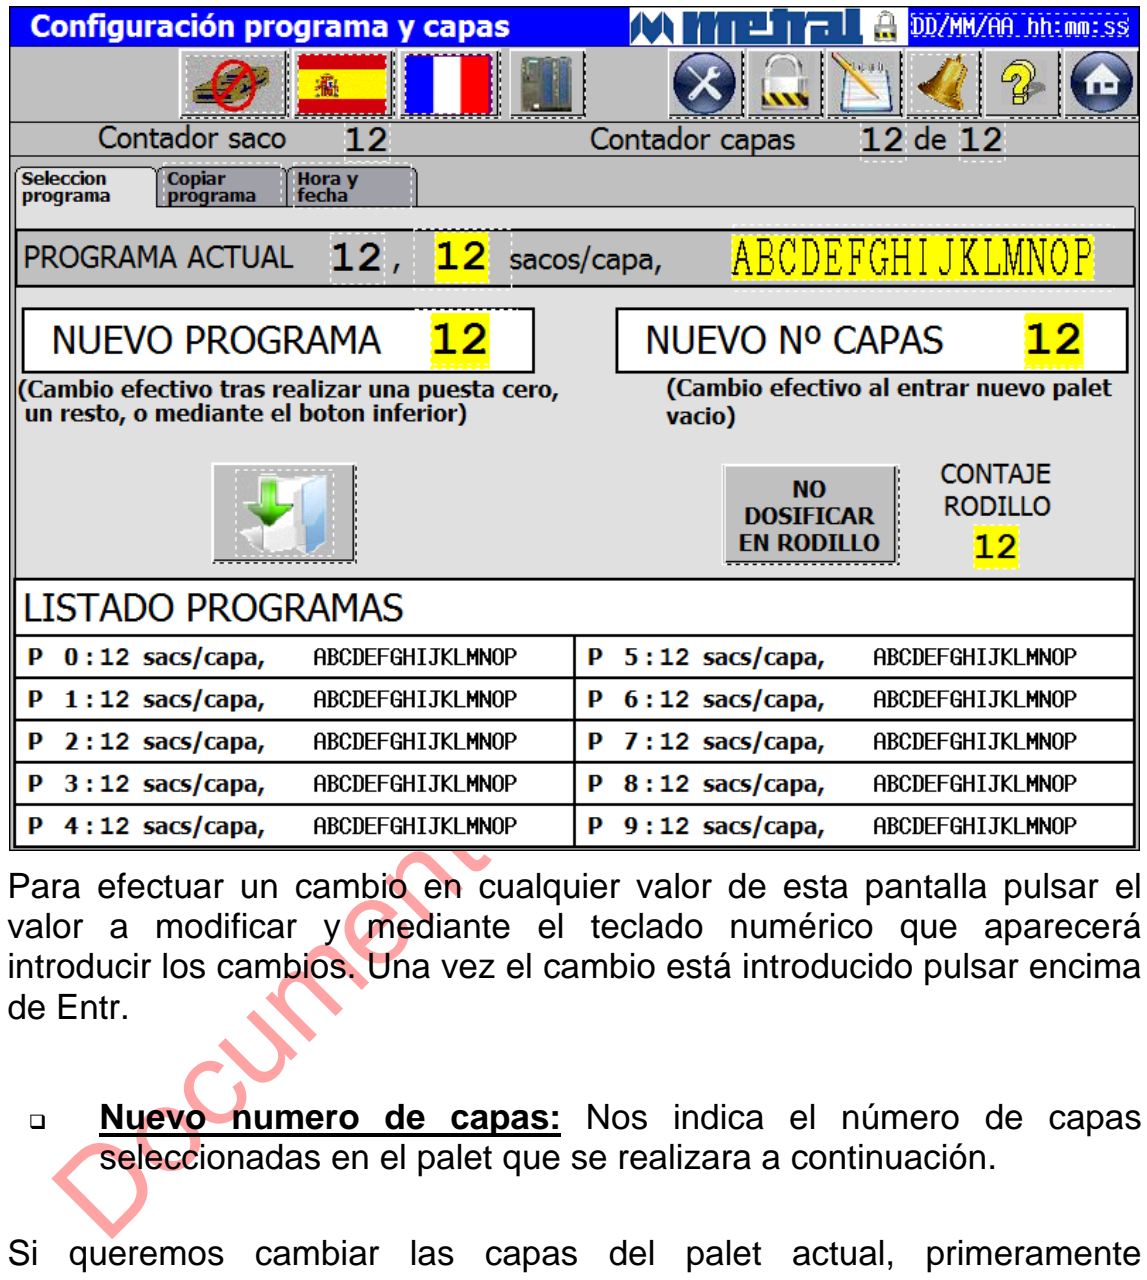
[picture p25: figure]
Documentación Preliminar; de Entr.

Para efectuar un cambio en cualquier valor de esta pantalla pulsar el valor a modificar y mediante el teclado numérico que aparecerá introducir los cambios. Una vez el cambio está introducido pulsar encima

Nuevo numero de capas: Nos indica el número de capas seleccionadas en el palet que se realizara a continuación.

Si queremos cambiar las capas del palet actual, primeramente deberemos situarnos encima del valor de Capas, y a través del teclado numérico entrar el valor nuevo y pulsar enter..

Este cambio será efectivo después de que un palet vacío entre en el transportador del elevador, es decir, que se haya completado un ciclo completo de paletizado.

# Documentación Preliminar

Programa actual: Nos indica que programa está ejecutando el paletizador en el momento actual dentro de todos los posibles.

Nuevo programa: Permite seleccionar un nuevo Programa, para ello pulsar encima del valor, a través del teclado númerico, entrar el valor nuevo y pulsar enter. Se efectuará en el siguiente palet, tras un cero, un resto o pulsando el botón si está el paletizador vacío.

Mediante las banderas de la barra superior podrá cambiar el idioma del terminal operador entre francés y español.

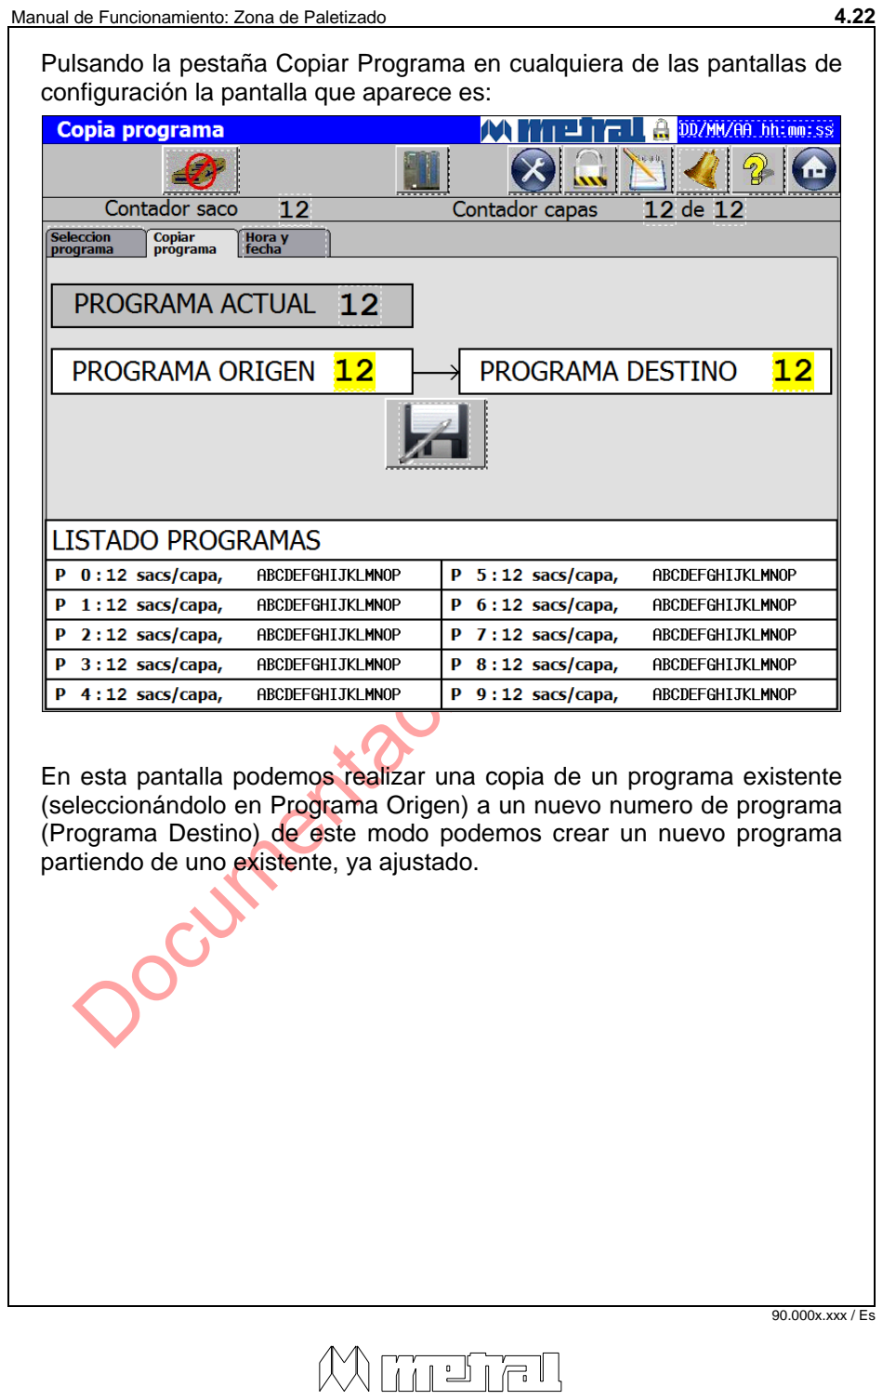
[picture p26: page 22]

# Documentación Preliminar

Pulsando la pestaña Copiar Programa en cualquiera de las pantallas de configuración la pantalla que aparece es:

En esta pantalla podemos realizar una copia de un programa existente (seleccionándolo en Programa Origen) a un nuevo numero de programa (Programa Destino) de este modo podemos crear un nuevo programa partiendo de uno existente, ya ajustado.

# Documentación Preliminar

Pulsando la pestaña Hora y Fecha en cualquiera de las pantallas de configuración la pantalla que aparece es:

En esta pantalla podemos modificar la fecha y la hora del terminal operador. Para ello pulsaremos encima del valor a modificar y mediante el teclado numérico que aparecerá realizaremos las modificaciones deseadas. Una vez finalizado el ajuste de la fecha y la hora pulsaremos encima de Validar Fecha / Hora.

### 3.5 PASSWORD:

Pulsando sobre el botón la pantalla que aparece es la siguiene:

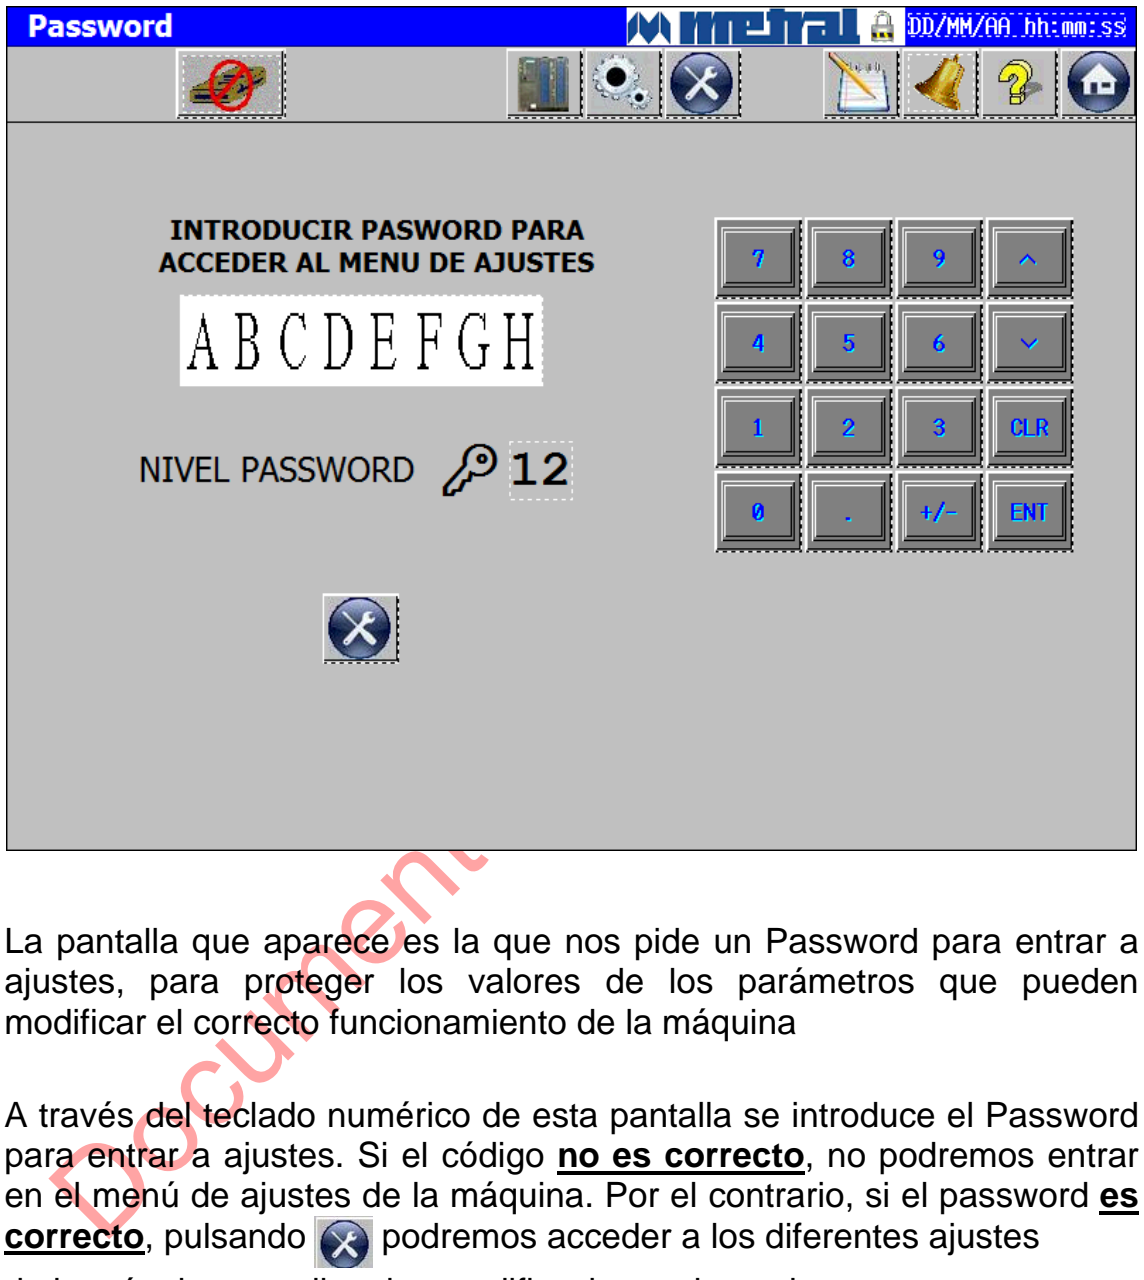
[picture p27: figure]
Documentación Preliminar

La pantalla que aparece es la que nos pide un Password para entrar a ajustes, para proteger los valores de los parámetros que pueden modificar el correcto funcionamiento de la máquina

A través del teclado numérico de esta pantalla se introduce el Password para entrar a ajustes. Si el código no es correcto, no podremos entrar en el menú de ajustes de la máquina. Por el contrario, si el password es correcto, pulsando podremos acceder a los diferentes ajustes
de la máquina y realizar las modificaciones deseadas.
NOTA: Es importante que este password de acceso sólo sea conocido por la persona designada por dirección como responsable de la instalación. En el momento de la puesta en marcha se dará el código de acceso.

### 3.6 AJUSTES

Pulsando el botón y habiendo introducido nivel de password la pantalla que aparece es la siguiente:

Estas pantallas nos muestran los tiempos de posicionamiento de los

Para modificar cualquier parámetro tan solo hay que pulsar con el dedo encima del valor que queramos modificar, automáticamente se mostrará una pantalla numérica, teclear el valor nuevo y pulsar enter.

Con los botones | podrá mover manualmente las cintas de
aplanado para poder hacer una prueba del prensado del saco.
Una vez escogida la posición deseada, se muestra el valor numérico en el valor de color azul, se puede modificar la posición de cero pulsando en el valor amarillo y modificándolo con el teclado numérico que aparecerá. Para colocar la cinta en la posición de cero pulsaremos en Reposicionar.

Estando situado en cualquier pantalla de ajustes y pulsando la pestaña Cinta Programada la pantalla que aparece es:

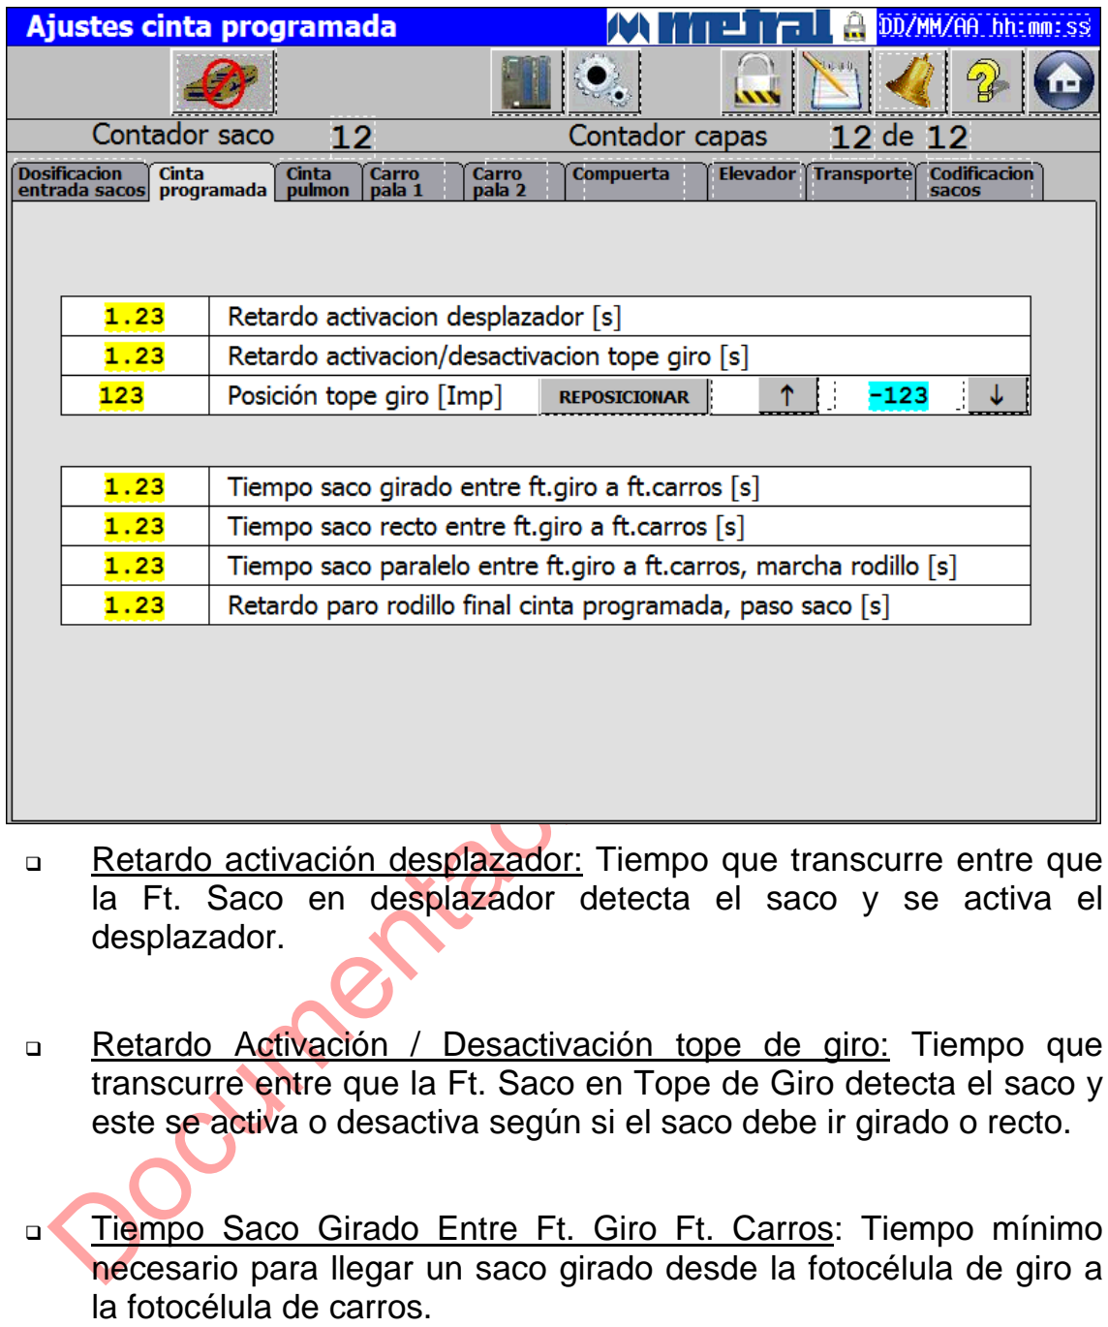
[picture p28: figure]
Documentación Preliminar; desplazador.; la fotocélula de carros.

| Retardo activación desplazador: Tiempo que transcurre entre que la Ft. Saco en desplazador detecta el saco y se activa el
| Retardo Activación / Desactivación tope de giro: Tiempo que transcurre entre que la Ft. Saco en Tope de Giro detecta el saco y este se activa o desactiva según si el saco debe ir girado o recto.
| Tiempo Saco Girado Entre Ft. Giro Ft. Carros: Tiempo mínimo necesario para llegar un saco girado desde la fotocélula de giro a
| Tiempo Saco Recto Entre Ft. Giro a Ft. Carros: Tiempo mínimo necesario para llegar un saco recto desde la fotocélula de giro a la fotocélula de carros.

# Documentación Preliminar

| Tiempo Saco Paralelo entre Ft. Giro a Ft. Carros, Marcha Rodillo: Tiempo mínimo necesario para llegar un saco paralelo desde la fotocélula de giro a la fotocélula de carros.
| Retardo paro Rodillo Final Cinta Programada, Paso Saco: Tiempo mínimo de funcionamiento del rodillo final de la banda programada al llegar un saco.

Estando situado en cualquier pantalla de ajustes y pulsando la pestaña Cinta Pulmón la pantalla que aparece es:

Estas pantallas nos muestran los tiempos de posicionamiento de los

Para modificar cualquier parámetro tan solo hay que pulsar con el dedo encima del valor que queramos modificar, automáticamente se mostrará una pantalla numérica, teclear el valor nuevo y pulsar enter.

| Retardo Marcha Cinta Pulmón en Saco no Fin de Semicapa: Tiempo de retardo entre el encendido del rodillo final cinta programada y la cinta pulmón para asegurar el correcto posicionado de los sacos en la cinta pulmón cuando no es el fin de la capa.
| Retardo Marcha Cinta Pulmón en Saco Fin de Semicapa: Tiempo de retardo entre el encendido del rodillo final cinta programada y la cinta pulmón para asegurar el correcto posicionado de los sacos en la cinta pulmón cuando es el fin de la capa.

# Documentación Preliminar

Posición Capa en Cinta Precapa: Tiempo que transcurre entre que la Ft. Seguridad Arrastre detecta la capa y la cinta precapa se detiene para posicionar los sacos correctamente.

Estando situado en cualquier pantalla de ajustes y pulsando la pestaña Carro Pala 1 la pantalla que aparece es:

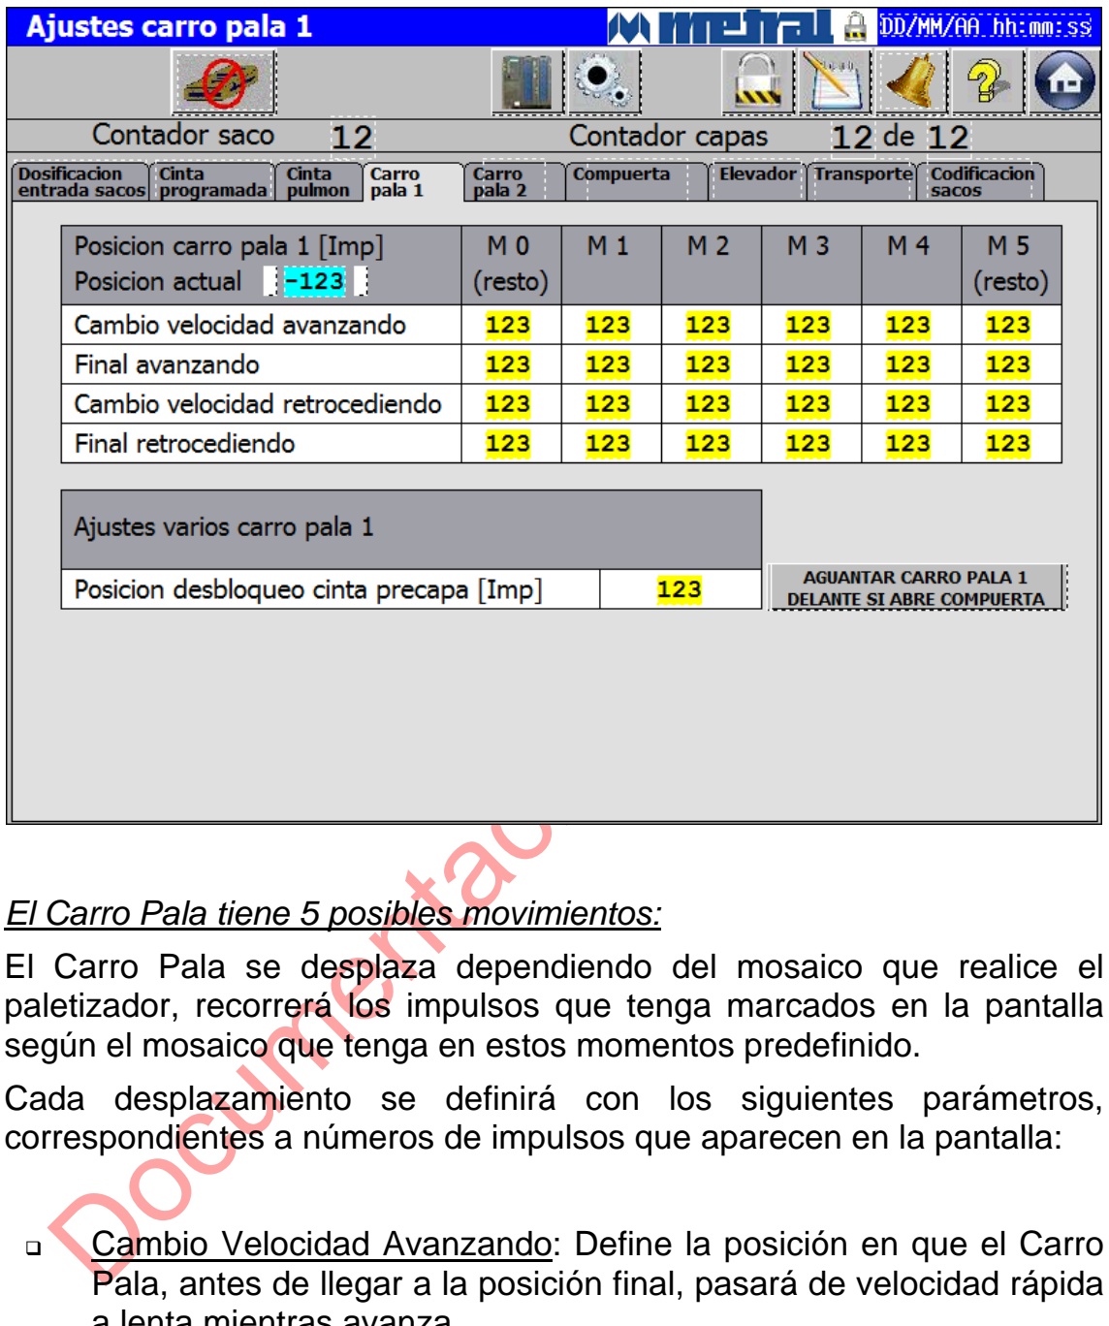
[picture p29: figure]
Documentación Preliminar

El Carro Pala tiene 5 posibles movimientos:
El Carro Pala se desplaza dependiendo del mosaico que realice el paletizador, recorrerá los impulsos que tenga marcados en la pantalla según el mosaico que tenga en estos momentos predefinido.
Cada desplazamiento se definirá con los siguientes parámetros, correspondientes a números de impulsos que aparecen en la pantalla:
| Cambio Velocidad Avanzando: Define la posición en que el Carro Pala, antes de llegar a la posición final, pasará de velocidad rápida a lenta mientras avanza.
| Final Avanzando: Marca la posición final del desplazamiento del Carro Pala.

# Documentación Preliminar

| Cambio Velocidad Retrocediendo: Define la posición en que el Carro Pala pasará de velocidad rápida a lenta antes de pararse al retroceder.
| Final Retrocediendo: Marca la posición final del desplazamiento del Carro Pala retrocediendo. Si es 0 volverá a la posición del detector reposo
| Posición Actual Carro Pala: Información de la posición actual del Carro Pala.
| Pos. Desbloqueo Cinta Precapa: La posición del carro pala 1 a la que queremos dar permiso para arrancar la cinta precapa.
| Aguantar / No Aguantar Carro Pala 1 Delante si Abre Compuerta: Si está seleccionada la opción aguantar carro pala 1 delante si abre compuerta, el carro pala 1 permanece en su posición “desplazado” aguantando los sacos si coincide cuando la compuerta está abriendo.

Estando situado en cualquier pantalla de ajustes y pulsando la pestaña Carro Pala 2 la pantalla que aparece es:

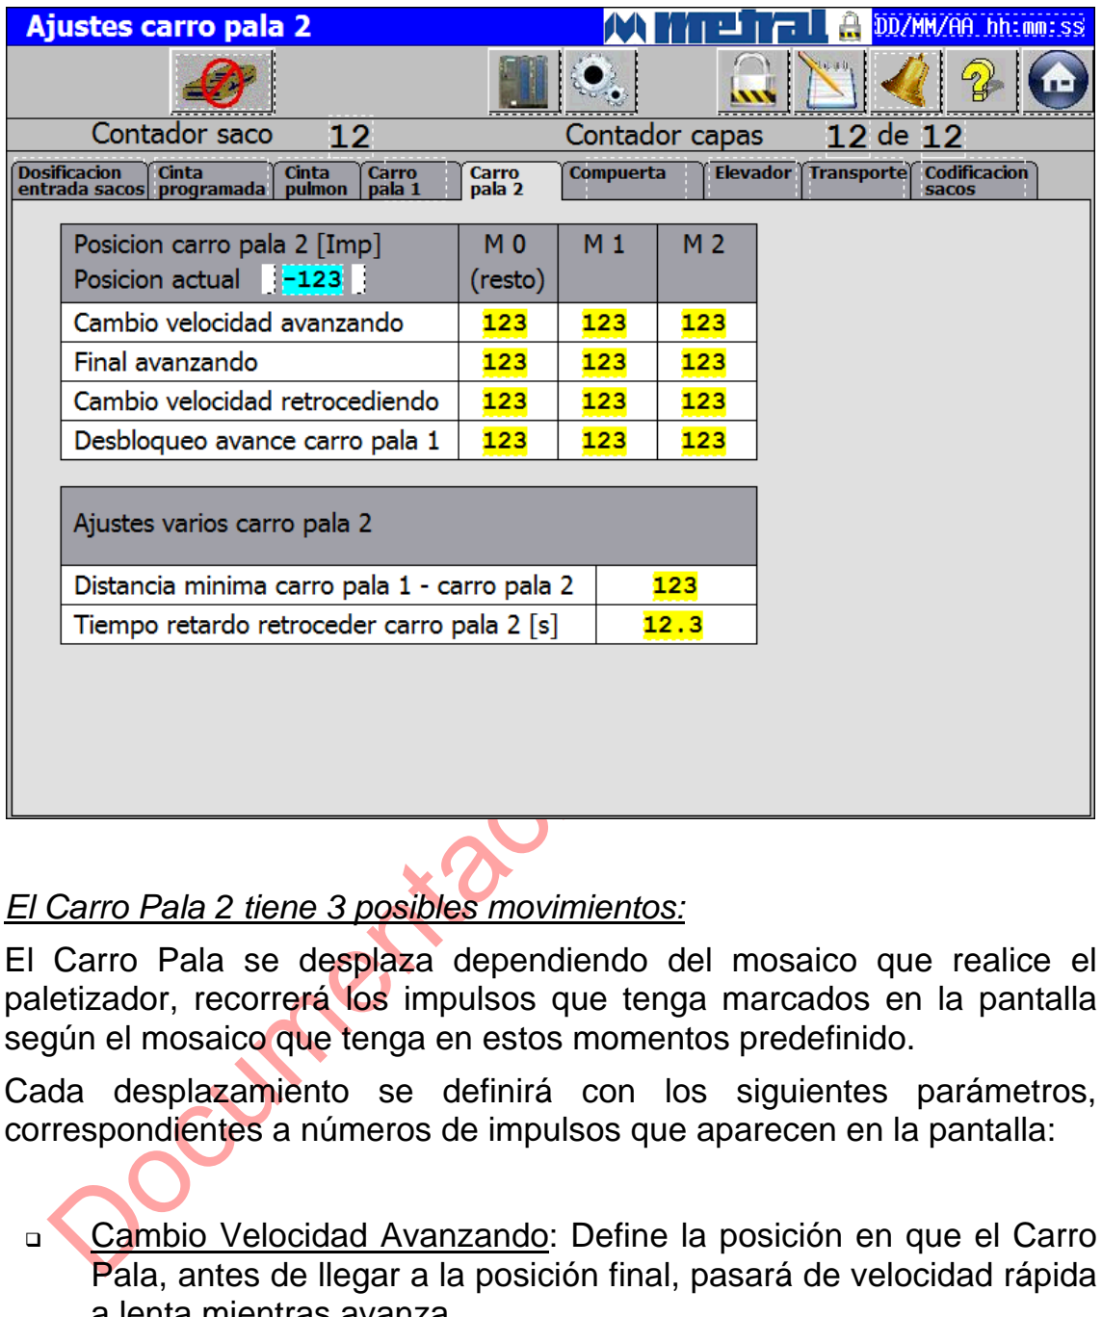
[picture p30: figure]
Documentación Preliminar

El Carro Pala 2 tiene 3 posibles movimientos:
El Carro Pala se desplaza dependiendo del mosaico que realice el paletizador, recorrerá los impulsos que tenga marcados en la pantalla según el mosaico que tenga en estos momentos predefinido.
Cada desplazamiento se definirá con los siguientes parámetros, correspondientes a números de impulsos que aparecen en la pantalla:
| Cambio Velocidad Avanzando: Define la posición en que el Carro Pala, antes de llegar a la posición final, pasará de velocidad rápida a lenta mientras avanza.
| Final Avanzando: Marca la posición final del desplazamiento del Carro Pala.

# Documentación Preliminar

| Cambio Velocidad Retrocediendo: Define la posición en que el Carro Pala pasará de velocidad rápida a lenta antes de pararse al retroceder.
| Posición Desbloqueo Avance Carro Pala 1: Es el retardo al arrancar el carro pala 1 desde que arranca el carro pala 2 con tal de no producir interferencias.
| Posición Actual Carro Pala 2: Información de la posición actual del Carro Pala 2.
| Distancia Mínima entre Carro Pala 1 y Carro Pala 2: Define la distancia mínima entre los dos carro pala para evitar interferencias.
| Tiempo Retardo Retroceder Carro Pala 2: Tiempo para que el carro pala 2 arranque hacia atrás para evitar interferencias.

Estando situado en cualquier pantalla de ajustes y pulsando la pestaña Compuerta la pantalla que aparece es:

| Posición Final Avanzando: Punto de parada de la compuerta en movimiento avanzando para quedar completamente cerrada.
| Posición Final Retrocediendo: Punto de parada de la compuerta en movimiento retrocediendo para quedar completamente abierta.
| Velocidad Avanzando: Velocidad de funcionamiento de la
| Velocidad Retrocediendo: Velocidad de funcionamiento de la compuerta en su movimiento retroceder.
| Velocidad Manual: Velocidad de funcionamiento de la compuerta cuando está trabajado en modo manual.

# Documentación Preliminar

| Tiempo Aceleración: Tiempo que transcurre entre que la compuerta empieza a moverse y alcanza la velocidad máxima.
| Tiempo Desaceleración: Tiempo que transcurre entre que la compuerta pasa de su velocidad máxima hasta quedar completamente detenido.
| Prensa Izquierda: En este ajuste podemos ver dos valores. El valor de color amarillo es el que indica el punto hasta donde avanzara la prensa izquierda (valor expresado en impulsos de encoder). El valor de color azul y precedido de un símbolo – es el que nos indica el punto actual de la prensa
| Prensa Derecha: En este ajuste podemos ver dos valores. El valor de color amarillo es el que indica el punto hasta donde avanzara la prensa derecha (valor expresado en impulsos de encoder). El valor de color azul y precedido de un símbolo – es el que nos indica el punto actual de la prensa.
| Impulsos Movimiento Final Prensas: Impulsos que se suman al cierre final de las prensas para corregir la capa cuando las compuertas empiezan a abrirse.
| Prensa frontal: En este ajuste podemos ver dos valores. El valor de color amarillo es el que indica el punto donde se posicionará la prensa frontal (valor expresado en impulsos de encoder). El valor de color azul y precedido de un símbolo – es el que nos indica el punto actual de la prensa. Podemos mover manualmente la prensa frontal con las dos flechas situadas al lado del valor posición actual. De este modo podemos colocar la prensa en el lugar deseado y una vez colocada copiar el valor posición actual a posición de cero.

Estando situado en cualquier pantalla de ajustes y pulsando la pestaña Elevador la pantalla que aparece es:

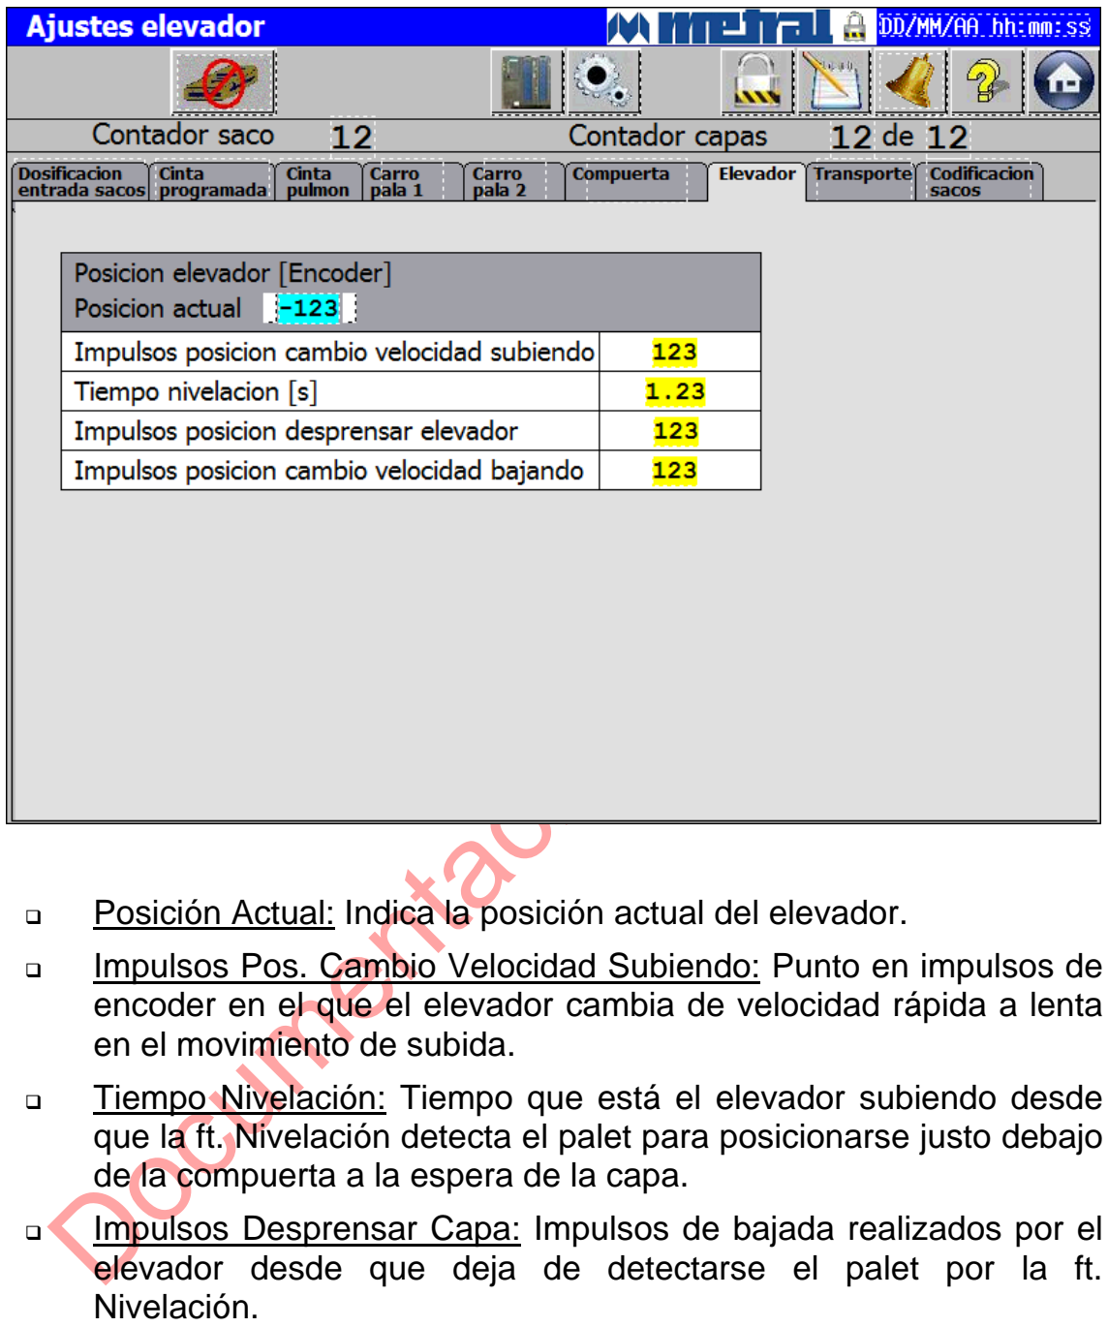
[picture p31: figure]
Documentación Preliminar; en el movimiento de subida.; de la compuerta a la espera de la capa.; Nivelación.

| Posición Actual: Indica la posición actual del elevador.
| Impulsos Pos. Cambio Velocidad Subiendo: Punto en impulsos de encoder en el que el elevador cambia de velocidad rápida a lenta
| Tiempo Nivelación: Tiempo que está el elevador subiendo desde que la ft. Nivelación detecta el palet para posicionarse justo debajo
| Impulsos Desprensar Capa: Impulsos de bajada realizados por el elevador desde que deja de detectarse el palet por la ft.
| Velocidad Bajada Capa: Velocidad de trabajo del elevador mientras está bajando la capa (Valor expresado en Revoluciones por Minuto)

Estando situado en cualquier pantalla de ajustes y pulsando la pestaña Transporte la pantalla que aparece es:

| Posición Palet en Espera: Tiempo que transcurre entre que la ft. Palet en Espera detecta el palet y los rodillos se detienen para
| Posición Palet en Elevador: Tiempo que transcurre entre que la ft. Palet en Elevador detecta el palet y el camino rodillos elevador se
| Posición Palet en Salida Elevador: Tiempo que transcurre entre que la ft: Palet en salida elevador detecta el palet y los rodillos se
| Posición Palet en Aplicador de Film: Tiempo que Transcurre entre que la Ft. Palet en Aplicador de Film detecta el palet y los rodillos del transportador se detienen para posicionar el palet correctamente.
| Longitud Film: Longitud en impulsos de la lámina de plástico que se aplica al palet vacío.
| Pos. Colocar Film Sobre Palet: Punto en impulsos de encoder en el que tiene que estar el carro arrastre film del aplicador para abrir las pinzas y soltar la lámina de film encima del palet.

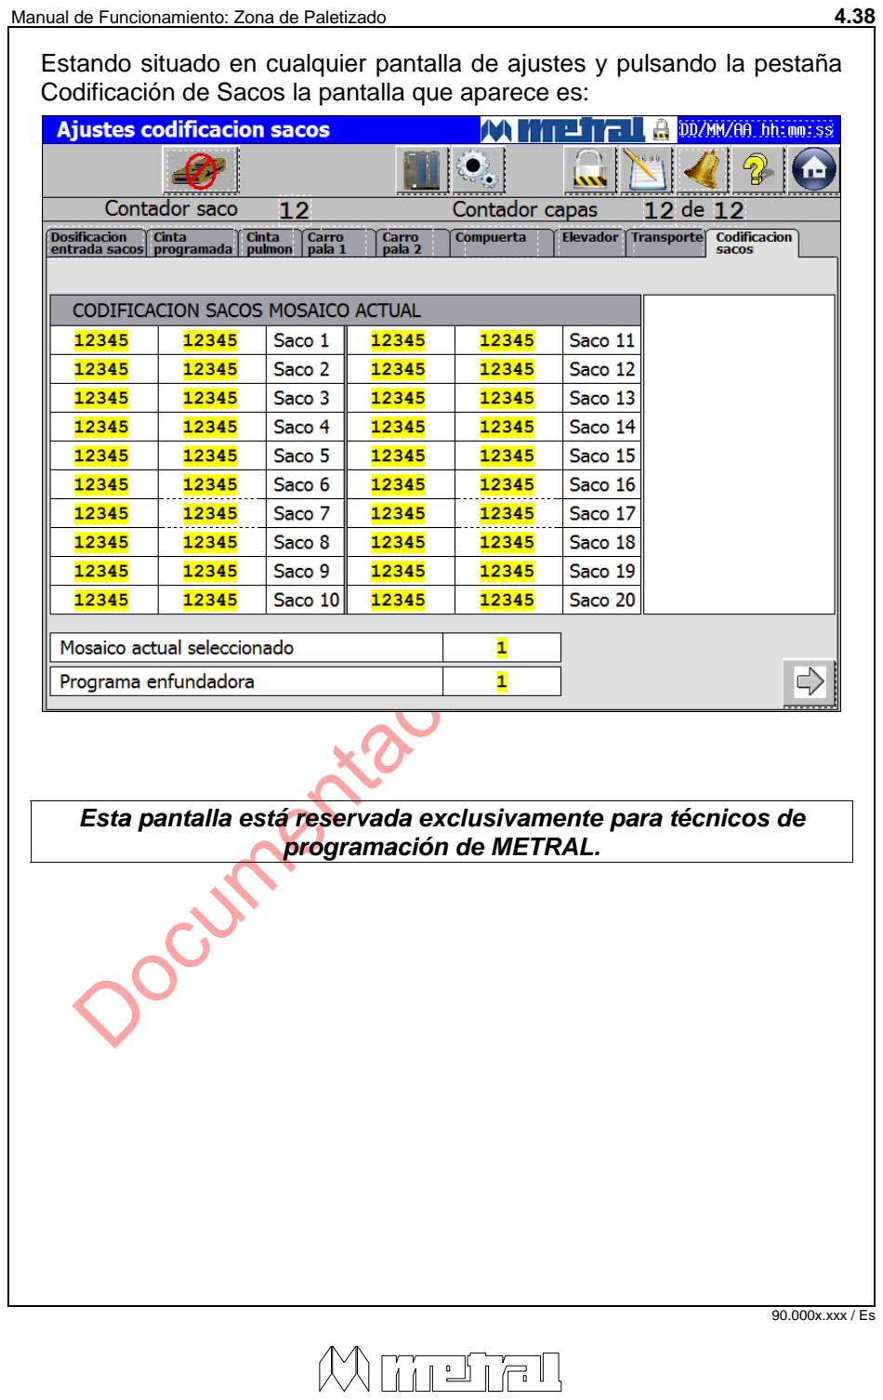
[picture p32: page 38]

# Documentación Preliminar

Estando situado en cualquier pantalla de ajustes y pulsando la pestaña Codificación de Sacos la pantalla que aparece es:

Esta pantalla está reservada exclusivamente para técnicos de programación de METRAL.

# Documentación Preliminar

Esta pantalla está reservada exclusivamente para técnicos de programación de METRAL.


# Documentación Preliminar

Esta pantalla está reservada exclusivamente para técnicos de programación de METRAL.


# Documentación Preliminar

Esta pantalla está reservada exclusivamente para técnicos de programación de METRAL.

# Documentación Preliminar

Esta pantalla está reservada exclusivamente para técnicos de programación de METRAL.


# Documentación Preliminar

Esta pantalla está reservada exclusivamente para técnicos de programación de METRAL.

# Documentación Preliminar

Esta pantalla está reservada exclusivamente para técnicos de programación de METRAL.


# Documentación Preliminar

### 3.7 PRODUCCIÓN

Pulsando sobre el botón la pantalla que aparece es la siguiene:

Esta pantalla nos proporciona información de los siguientes parámetros:

| Sacos: Valor que nos indica el total de sacos que han entrado en la máquina desde el último reset realizado.
| Palets: Valor que nos indica el número de palets completos realizados desde el último reset realizado.
| Tiempo en Marcha (Parcial): Tiempo que lleva el paletizador en marcha desde el ultimo reset de contadores.

RESET: Pulsando sobre esta opción realizamos un cero de los contadores.

# Documentación Preliminar

| Total Sacos: Valor que nos indica el total de sacos que han entrado en la máquina.
| Total Palets: Valor que nos indica el número de palets completos realizados.
| Tiempo en Marcha (Total): Tiempo que lleva el paletizador en marcha desde que se puso en marcha la instalación.
| Sacos Último Minuto: Nº de sacos producidos en el último minuto.
| Sacos / Minuto: Producción de la máquina en sacos/minuto.
| Sacos / Hora: Producción de la máquina en sacos/hora. Cálculo realizado multiplicando los sacos en último minuto por 60.

## 4. MENU AYUDA:


# Documentación Preliminar

Pulsando el botón podrá visualizar la ayuda del sistema.
En esta ayuda podrá ver una descripción detallada de los botones de función de las diferentes pantallas.

## 5. MODO DE FUNCIONAMIENTO SEMIAUTOMÁTICO

# Documentación Preliminar

Acceder al modo de funcionamiento SEMIAUTOMÁTICO mediante el selector negro AUT/MAN/SEMI

De esta forma la pantalla que nos aparecerá en el terminal de operador será:

| Nuevo Contador Capas: Nos permite modificar el número de capas actuales en el elevador.
| Nuevo Contador Saco: Nos permite modificar el número de saco actual de la máquina.

1

# Documentación Preliminar

La modificación de estos contadores se realizará cuando se produzca algún tipo de anomalía. Para ello seguir los siguientes pasos:
1. Parar la entrada de sacos.
2. Para modificar el contador de sacos, primeramente deberemos vaciar la banda programada.
3. El vaciado de la banda programada se debe realizar en modo semiautomático utilizando las opciones disponibles. En el caso de que el último saco entrado (valor a colocar en contador) sea un saco en paralelo (saco desplazado) el saco debe colocarse en el final de la banda programada en la posición de espera del siguiente saco.

Para modificar Contador de Sacos, nos situaremos en “Nuevo Contador Sacos” y automáticamente se mostrará una pantalla numérica, entrar el número de saco actual y pulsar enter. Seguidamente pulsar validar y automáticamente se cambiará el valor actual por el valor nuevo. Si no pulsamos validar las modificaciones no se realizarán.

Al pulsar validar el valor introducido en el “Nuevo Contador Sacos” actualiza automáticamente el valor de “Contador Sacos”.

Además se muestra la visualización de los sacos en el momento actual.

Ejemplo: pulsando el botón la máquina realiza un movimiento completo del carro pala 1 como si tuviera una semicapa preparada para avanzar a la zona de las compuertas.

Al activar cualquiera de los movimientos de la zona se realiza un RESET de la zona seleccionada.


Presionando en el botón se mostrará
este menú de ayuda en el que podrá ver
los pasos a seguir para trabajar en semiautomático

1


# Documentación Preliminar

Pulsando Siguiente la pantalla que aparece es:

Mediante los botones reset podrá solucionar posibles errores en las fotocélulas de cada uno de los caminos, o vaciar o confirmar el vaciado de dichos rodillos / transportadores.

## 6. MODO DE FUNCIONAMIENTO MANUAL

Este modo de funcionamiento sólo debe ser utilizado para realizar comprobaciones y ajustes. NO sirve para realizar el proceso productivo para el cual ha sido diseñada la máquina.
Acceder al modo de funcionamiento MANUAL mediante el selector negro AUT/MAN/SEMI

De esta forma la pantalla que nos aparecerá en el terminal de operador

Pulsando los botones que hacen referencia al movimiento deseado y seguidamente el botón Marcha del cuadro de mando se realizarán los movimientos manualmente.
Cuando un componente se ponga en movimiento se iluminará de color verde la lámpara que le representa.


# Documentación Preliminar

# Documentación Preliminar

## 7. FUNCIONES ESPECIALES

### 7.1 RESTO (PULSADOR AMARILLO DEL CUADRO DE MANDO)

ACCIÓN
Detiene la dosificación de sacos y sólo paletiza los que quedan en la cinta programada, en zona de precapa y encima de la compuerta. Luego la máquina evacua automáticamente el palet, aunque esté incompleto, inicia un nuevo palet poniendo a cero el contador de capas.

APLICACIÓN
Final de producción o de serie del producto, defecto de contaje, por entrar sacos rotos, vacíos o cualquier otra causa, con la consiguiente malformación del palet.

MODO DE REALIZARLO
Con la máquina en funcionamiento automático pulsar el botón RESTO del panel de control del paletizador. Durante dos segundos hasta que aparezca en la pantalla principal (nº1) “Resto en Ejecución”.

SECUENCIA
Se detiene la dosificación de sacos. Después de un tiempo para asegurar que la cinta programada esté vacía, se transfieren los sacos que haya al palet (a partir de este momento los sacos que entren pertenecerán al siguiente palet). Sale el palet del elevador.

En el momento que en la pantalla aparece la indicación RESTO EN EJECUCIÓN, ya es efectivo.

# Documentación Preliminar

### 7.2 PUESTA A CERO (PULSADOR AZUL DEL CUADRO DE

MANDO)

ACCIÓN
Realiza un borrado de los registros, contadores y memorias internas, con tal de poner la máquina en posición de inicio.

APLICACIÓN
Cuando se han efectuado manipulaciones en manual de distintos elementos y queremos asegurarnos que la máquina iniciará en automático por el principio, como solución de emergencia por "desprogramación" o mal funcionamiento.

MODO DE REALIZARLO
| La máquina debe estar parada (módulo seguridad desactivado) y en funcionamiento automático.
| Ausencia de sacos en la parte superior de la máquina.
| Palets posicionados delante de fotocélulas..

Pulsar el pulsador de color azul CERO durante unos segundos, hasta que aparezca en la pantalla principal (nº 1), Cero.
Para CERO almacén utilizar pulsador pantalla reset Almacén.

# Documentación Preliminar

## 8. FUNCIONES DE SEGURIDAD

La instalación ha sido diseñada de acuerdo con la normativa europea de seguridad aplicable.

A continuación se presenta un esquema de las funciones de seguridad que incorporan las máquinas para su uso seguro:

Desactivado paro por
violación de la zona
peligrosa

Funcionamiento de la
màquina con mando
sensitivo
Selector de modo de
funcionamiento en modo
manual

PARO DE
EMERGENCIA
INMEDIATO

Paro por
violación de la zona
peligrosa

Pulsador panel de mando
Paro de emergencia
| El sistema de parada de emergencia tiene prioridad sobre todas las funciones.
| El rearme de la parada de emergencia no provoca un nuevo arranque. Sólo autoriza a realizarlo.
| MUY IMPORTANTE
| En ningún caso deben hacerse manipulaciones en la máquina sin tener desconectadas todas las fuentes de alimentación de la máquina (eléctrica y aire comprimido).

# Documentación Preliminar

Todos los sistemas y componentes aplicados a la seguridad de la máquina cumplen las disposiciones de las normas EN 292 y EN 60204-
1. En particular, el sistema de parada de emergencia está diseñado según la norma EN 418.
NUNCA | DESACTIVAR, | SUPRIMIR | O | MANIPULAR | LOS
DISPOSITIVOS DE SEGURIDAD

No rearrancar la máquina hasta conocer el motivo del paro de emergencia.

Comprobar que ninguna persona se encuentre dentro de la zona restringida antes de desbloquear el paro y activar otra vez el proceso productivo.

## 9. AVERÍAS, ALARMAS Y FALLOS

# Documentación Preliminar

Mientras la máquina trabaja se hace una comprobación lógica permanente de todos los sensores y sistemas de seguridad, de manera que si alguno de ellos funcionase de forma defectuosa, se activaría la alarma correspondiente.
Para poder acceder a los avisos o alarmas del sistema tenemos que pulsar el botón durante el funcionamiento automático.

Esta pantalla nos mostrará el tipo de alarma que se ha realizado, además nos mostrará las posibles soluciones para dicha alarma.


# Documentación Preliminar

Pulsando SIGUIENTE, la pantalla que nos aparece es:

Esta es una pantalla de información, registra todas las alarmas que se han producido durante el funcionamiento en automático.

# Documentación Preliminar

## 10. INSTALACIÓN DE SEGURIDAD

Se ha realizado un sistema de seguridad para toda la instalación, cumpliendo con la directiva 89-392-CE y las normas EN-292, EN-294, EN-414, EN-418 y EN-60204.

Paro de emergencia.
Este tipo de parada efectúa un corte inmediato de las salidas del autómata que actúan sobre los actuadores de la máquina, en este caso la línea de ensacado, y un corte eléctrico temporizado, de las salidas del autómata que actúan sobre la alimentación de los variadores, electro válvula de seguridad de aire y algunos movimientos neumáticos.
Esta parada se realiza al recibir señal del pulsador rojo PARO DE EMERGENCIA, del panel de control principal del ensacado.
También se efectuará una parada de emergencia al abrir cualquier puerta de acceso a la zona de seguridad de la máquina. Se han instalado unas fotocélulas de seguridad que al detectar cualquier persona que acceda a la zona de seguridad, realizará una parada de emergencia.
El único modo de volver a poner en funcionamiento la línea de ensacado una vez recibida una de estas señales, es acudir al panel de control principal y realizar un rearme de la instalación a través del pulsador rasante de color verde REARME DE SEGURIDAD.

IMPORTANTE: El rearme de la línea de paletizado sólo puede ser utilizado por una persona conocerá de los riesgos de la máquina y que esté autorizada por dirección para utilizarlo.

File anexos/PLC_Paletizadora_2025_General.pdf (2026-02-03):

CEMI Automatización | RDC
17/11/2025 | 1 / 97 | PLC_Paletizadora.cxp

000000
(000000)

[Nombre de programa : General]

[Nombre de sección : _Inicio_Salto]

Salto (si el PLC de seguridad no esta OK )

I: 3.03

OLD_X16
PLC
seguridad
OK=1

JMP
(004)
#0

17/11/2025 | 2 / 97 | PLC_Paletizadora.cxp

000000
(000003)

[Nombre de programa : General]

[Nombre de sección : Cargador_pallets]

Secuencia

CF113

P_On
Indicador
de
siempre
ON

MLPX
(076)
D300
#0

W50

[OP1]
Decodificador
secuencia
cargador de
pallets
<cD00300>
c0007 c0014
c0021 c0025
c0033 c0040
c0043 c0050
c0057 c0064
[OP2]
[OP3]
<W050.00>
a0005
<W050.01>
a0008
<W050.02>
a0015
<W050.03>
a0022
<W050.04>
a0026
<W050.05>
a0034
<W050.06>
a0041 a0075
<W050.07>
a0044
<W050.08>
a0051
<W050.09>
a0058

000001
(000005)

Paso 0 - Espera inicio

W50.00

Paso 0 -
espero
Inicio

301.00

Automátic
o activo

MOV
(021)
&1
D300

[OP1]
[OP2]
Decodificador
secuencia
cargador de
pallets
<cD00300>
c0004 c0014
c0021 c0025
c0033 c0040
c0043 c0050
c0057 c0064

000002
(000008)

Paso 1 - Entrar Puas

W50.01

Paso 1
-entrar
puas

I: 2.03

OLD_X50
Puas
dentro

TIM

0217
#7

[OP1] Auxiliar

<T0217(bit)>
a0013
[OP2]

T0217

Auxiliar

MOV
(021)
&2
D300

[OP1]
[OP2]
Decodificador
secuencia
cargador de

17/11/2025 | 3 / 97 | PLC_Paletizadora.cxp

pallets
<cD00300>
c0004 c0007
c0021 c0025
c0033 c0040
c0043 c0050
c0057 c0064

000003
(000015)

Paso 2 - Bajar puas

W50.02

Paso 2 -
Bajar
puas

I: 2.07

OLD_X54
Puas
abajo

TIM

0218
#7

[OP1] Auxiliar

<T0218(bit)>
a0020
[OP2]

T0218

Auxiliar

MOV
(021)
&3
D300

[OP1]
[OP2]
Decodificador
secuencia
cargador de
pallets
<cD00300>
c0004 c0007
c0014 c0025
c0033 c0040
c0043 c0050
c0057 c0064

000004
(000022)

paso 3 - Subir puas al medio

W50.03

Paso 3 -
Subir
puas
medio

I: 2.06

OLD_X53
Puas
centro

TIM

0219
#0

[OP1] Auxiliar

[OP2]

MOV
(021)
&4
D300

[OP1]
[OP2]
Decodificador
secuencia
cargador de
pallets
<cD00300>
c0004 c0007
c0014 c0021
c0033 c0040
c0043 c0050
c0057 c0064

000005
(000026)

Paso 4 - Puas salir

W50.04

Paso 4 -
Puas salir

TIM

0232
#8

[OP1]
auxiliar
[OP2]

I: 2.04

OLD_X51
Puas
fuera

TIM

0220
#3

[OP1] Auxiliar

<T0220(bit)>
a0032
[OP2]

T0220

Auxiliar

MOV
(021)
&5
D300

[OP1]
[OP2]
Decodificador
secuencia
cargador de
pallets
<cD00300>

17/11/2025 | 4 / 97 | PLC_Paletizadora.cxp

c0004 c0007
c0014 c0021
c0025 c0040
c0043 c0050
c0057 c0064

000006
(000034)

Paso 5 - Puas Subir

W50.05

Paso 5 -
puas subir

I: 2.05

OLD_X52
Puas
arriba

TIM

0221
#6

[OP1] Auxiliar

<T0221(bit)>
a0039
[OP2]

T0221

Auxiliar

MOV
(021)
&6
D300

[OP1]
[OP2]
Decodificador
secuencia
cargador de
pallets
<cD00300>
c0004 c0007
c0014 c0021
c0025 c0033
c0043 c0050
c0057 c0064

000007
(000041)

Paso 6 - Pallet listo para sacar

W50.06

Paso 6 -
Pallet listo
para
sacar -
Secuencia
cargador

W80.06

Paso 6 -
Ok salio
pallet de
cargado,
Muevo
cinta film

MOV
(021)
&7
D300

[OP1]
[OP2]
Decodificador
secuencia
cargador de
pallets
<cD00300>
c0004 c0007
c0014 c0021
c0025 c0033
c0040 c0050
c0057 c0064

000008
(000044)

Paso 7 - Bajar puas

W50.07

Paso 7 -
bajar puas

I: 2.07

OLD_X54
Puas
abajo

TIM

0222
#3

[OP1] Auxiliar

<T0222(bit)>
a0049
[OP2]

T0222

Auxiliar

MOV
(021)
&8
D300

[OP1]
[OP2]
Decodificador
secuencia
cargador de
pallets
<cD00300>
c0004 c0007
c0014 c0021
c0025 c0033
c0040 c0043
c0057 c0064

000009
(000051)

Paso 8 - Entrar puas

W50.08

Paso 8 -
Entrar

I: 2.03

OLD_X50
Puas

TIM

0223
#3

[OP1] Auxiliar

<T0223(bit)>

17/11/2025 | 5 / 97 | PLC_Paletizadora.cxp
puas | dentro | a0056
[OP2]
| T0223
| Auxiliar

MOV
(021)
&9
D300

[OP1]
[OP2]
| | Decodificador secuencia cargador de pallets

<cD00300>
c0004 c0007
c0014 c0021
c0025 c0033
c0040 c0043
c0050 c0064

000010
(000058)

Paso 9 - espero reinicio de ciclo

W50.09

Paso 9 -
espero
reinicio de
ciclo

I: 0.00

Pres_pall
et
Presencia
de pallet
en
trasnporte
(fotocelda
)

TIM

0224
#200

[OP1]
Auxiliar no hay
pallet
<T0224(bit)>
a0063
[OP2]

T0224

Auxiliar no
hay pallet

MOV
(021)
&1
D300

[OP1]
[OP2]
Decodificador
secuencia
cargador de
pallets
<cD00300>
c0004 c0007
c0014 c0021
c0025 c0033
c0040 c0043
c0050 c0057

17/11/2025 | 6 / 97 | PLC_Paletizadora.cxp

000000
(000066)

[Nombre de programa : General]

[Nombre de sección : Rodillos_centrador]

Secuencia camas de rodillos

CF113

P_On
Indicador
de
siempre
ON

MLPX
(076)
D400
#0

W80

[OP1]
Decodificador
secuencia
rodillos
<cD00400>
c0070 c0072
c0080 c0084
c0090 c0097
c0101 c0107
c0110 c0114
[OP2]
[OP3]
<W080.00>
a0068
<W080.02>
a0073
<W080.04>
a0081
<W080.06>
a0042 a0091
<W080.08>
a0098
<W080.10>
a0102 a0428
<W080.12>
a0108 a0122
<W080.14>
a0111

000001
(000068)

Paso 0 - Espero inicio

W80.00

Paso 0 -
espero
inicio

301.00

Automátic
o activo

MOV
(021)
&2
D400

[OP1]
[OP2]
Decodificador
secuencia
rodillos
<cD00400>
c0067 c0072
c0080 c0084
c0090 c0097
c0101 c0107
c0110 c0114
I: 0.00

Pres_pall
et
Presencia
de pallet
en
trasnporte
(fotocelda
)

MOV
(021)
&10
D400

[OP1]
[OP2]
Decodificador
secuencia
rodillos
<cD00400>
c0067 c0070
c0080 c0084
c0090 c0097
c0101 c0107
c0110 c0114

000002
(000073)

Paso 2 - Espero OK de cargador para mover

W80.02

Paso 2 -
espero Ok
cargador
para

W50.06

Paso 6 -
Pallet listo
para
sacar -

I: 0.00

Pres_pall
et
Presencia
de pallet

TIM

0226
#5

[OP1]
Auxiliar
<T0226(bit)>
a0079
[OP2]

mover; Secuenci; cargador; en trasnporte (fotocelda ); Auxiliar; MOV (021) &4 D400; [OP1] [OP2] Decodificador secuencia rodillos <cD00400> c0067 c0070 c0072 c0084 c0090 c0097 c0101 c0107 c0110 c0114; Paso 4 - Muevo cintas; Paso 4 - muevo cintas; Pres_pall et Presencia de pallet en trasnporte (fotocelda ); MOV (021) &6 D400; [OP1] [OP2] Decodificador secuencia rodillos <cD00400> c0067 c0070 c0072 c0080 c0090 c0097 c0101 c0107 c0110 c0114; Pallet_en _cargador; Pallet en cargador; TIM; [OP1] Auxiliar falla; <T0234(bit)> a0088 [OP2]; Auxiliar falla; P_Off Indicador de siempre OFF; MOV (021) &14 D400; [OP1] [OP2] Decodificador secuencia rodillos <cD00400> c0067 c0070 c0072 c0080 c0084 c0097 c0101 c0107 c0110 c0114; Paso 6 - Ok salio pallet de cargado, Muevo cinta film; [OP1] Centrador longitudinal <T0227(bit)> a0096 [OP2] Tiempo HMI; Centrador longitudin al; MOV (021) &8 D400; [OP1] [OP2] Decodificador secuencia rodillos <cD00400> c0067 c0070 c0072 c0080 c0084 c0090 c0101 c0107

17/11/2025 | 7 / 97 | PLC_Paletizadora.cxp

Paso 6 - Ok salio pallet de cargado, Muevo cinta film

Paso 8 - Activo centrador; Paso 8 - activo centrador; TIM; [OP1] Auxiliar tiempo; centrador activo <T0228(bit)> a0100 [OP2]; Auxiliar tiempo centrador activo; MOV (021) &10 D400; [OP1] [OP2] Decodificador secuencia rodillos <cD00400> c0067 c0070 c0072 c0080 c0084 c0090 c0097 c0107 c0110 c0114; Paso 10 - Selección; Paso 10 - Espero OK de maq film; Hab_FILM Habilitació n proceso máquina film; Paso 14 - termino maq film, cero; MOV (021) &12 D400; [OP1] [OP2] Decodificador secuencia rodillos <cD00400> c0067 c0070 c0072 c0080 c0084 c0090 c0097 c0101 c0110 c0114; Paso 12 - Pallet listo para sacar; Paso 12 - pallet listo para sacar; Paso 6 - movimient o OK - Secuenci; entrada elevador; MOV (021) &2 D400; [OP1] [OP2] Decodificador secuencia rodillos <cD00400> c0067 c0070 c0072 c0080 c0084 c0090 c0097 c0101 c0107 c0114; Paso 14 - Pallet trabado; Paso 14 - Falla, pallet trabajo; Pallet_en _cargador; Pallet en cargador; Boton reconocim iento HMI; MOV (021) &4 D400; [OP1] [OP2] Decodificador secuencia rodillos <cD00400> c0067 c0070 c0072 c0080

17/11/2025 | 8 / 97 | PLC_Paletizadora.cxp

17/11/2025 | 9 / 97 | PLC_Paletizadora.cxp

c0084 c0090
c0097 c0101
c0107 c0110

[Nombre de programa : General]; [Nombre de sección : Rodillos_entrada_elevador]; Secuencia rodillos de salida; P_On Indicador de siempre ON; MLPX (076) D410 #1000 W150; [OP1] Decodificador secuencia rodillos salida <cD00410> c0120 c0127 c0136 c0143 c0153 c0176 c0183 c0195 c0198 c0202 c0205 [OP2] [OP3] <W150.00> a0118 <W150.02> a0121 <W150.04> a0128 b0144 <W150.06> a0109 a0146 <W150.08> a0154 b0184 <W150.10> a0192 <W150.12> a0196 a0272; Paso 0 -Inicio; Paso 0 - Inicio; Automátic o activo; MOV (021) &2 D410; [OP1] [OP2] Decodificador secuencia rodillos salida <cD00410> c0117 c0127 c0136 c0143 c0153 c0176 c0183 c0195 c0198 c0202 c0205; Paso 2 - Espero OK de cinta anterior; Paso 2 - Espero OK cinta anterior; Paso 12 - pallet listo para sacar; OLD_X55 FT. Pallet en espera; = (300) D420 &0 [OP1] Decodifica dor salida [OP2]; TIM; [OP1] T espera liberación <T0236(bit)> a0126 [OP2]; T espera liberación; MOV (021) &4 D410; [OP1] [OP2] Decodificador secuencia rodillos salida <cD00410> c0117 c0120 c0136 c0143

17/11/2025 | 10 / 97 | PLC_Paletizadora.cxp

Paso 4 - Muevo hasta sensor; Muevo hasta sensor; OLD_X55 FT. Pallet en espera; SET; Auxiliar Sensor <150.05> a0133; Auxiliar Sensor; TIMH (015) 0244 #10; [OP1] T auxiliar <T0244(bit)> a0135 [OP2]; T auxiliar; MOV (021) &6 D410; [OP1] [OP2] Decodificador secuencia rodillos salida <cD00410> c0117 c0120 c0127 c0143 c0153 c0176 c0183 c0195 c0198 c0202 c0205; RSET; TIM; [OP1] Tiempo falla, pallet trabado <T0116(bit)> a0142 [OP2]; Tiempo falla, pallet trabado; MOV (021) &25 D410; [OP1] [OP2] Decodificador secuencia rodillos salida <cD00410> c0117 c0120 c0127 c0136 c0153 c0176 c0183 c0195 c0198 c0202 c0205; Paso 6 - Espero elevador para entrar; Paso 6 - movimient o OK - Secuencia entrada elevador; Ciclo elevador - paso 0 - bajar lento; Elevador abajo; [OP1] auxiliar <T0230(bit)> a0152 [OP2]

17/11/2025 | 11 / 97 | PLC_Paletizadora.cxp

auxiliar; MOV (021) &8 D410; [OP1] [OP2] Decodificador secuencia rodillos salida <cD00410> c0117 c0120 c0127 c0136 c0143 c0176 c0183 c0195 c0198 c0202 c0205; Paso 8 - Entrar a elevador; Paso 8 - entrar a elevador; MOV (021) &0 D5004; [OP1] [OP2] Auxiliar <cD05004> c0168 c0175 c0278; OLD_X57 FT pallet en elevador; SET; Sensor <150.00> a0162 a0165 a0173; Sensor; Activar bandera <150.01> a0188; OLD_Y22 Rodillos palets; P_0_1s Bit de pulso de reloj de 0.1 segundos; Auxiliar <cD05004> c0157 c0175 c0278; OLD_X56 FT seguridad entrada elevador; OLD_X60 FT seguridad salida elevador; >= (325) D5004 D6000 [OP1] Auxiliar [OP2] Pulsos/tie mpo para parar rodillos; MOV (021) &10 D410; [OP1] [OP2] Decodificador secuencia rodillos salida <cD00410> c0117 c0120 c0127 c0136 c0143 c0153 c0183 c0195 c0198 c0202 c0205; RSET; P_Off Indicador de siempre OFF; OLD_X60 FT; P_Off Indicador; MOV (021) &26 D410; [OP1] [OP2] Decodificador

17/11/2025 | 12 / 97 | PLC_Paletizadora.cxp

17/11/2025 | 13 / 97 | PLC_Paletizadora.cxp

seguridad
salida
elevador

de
siempre
OFF

secuencia
rodillos salida
<cD00410>
c0117 c0120
c0127 c0136
c0143 c0153
c0176 c0195
c0198 c0202
c0205

000007
(000184)

W150.08

Paso 8 -
entrar a
elevador

RSET

150.00

Sensor
<150.00>
a0162 a0165
a0173

CF114

P_Off
Indicador
de
siempre
OFF

RSET

150.01

Activar bandera
<150.01>
a0188

000008
(000188)

150.01

Activar
bandera

TIM

0239
#40

[OP1]
T subir bandela
<T0239(bit)>
a0190
[OP2]

T0239

T subir
bandela

RSET

150.01

Activar bandera
<150.01>
a0188

000009
(000192)

Paso 10 - Tiempo

W150.10

Paso 10 -
Tiempo

TIM

0231
#5

[OP1] Auxiliar

<T0231(bit)>
a0194
[OP2]

T0231

Auxiliar

MOV
(021)
&12
D410

[OP1]
[OP2]
Decodificador
secuencia
rodillos salida
<cD00410>
c0117 c0120
c0127 c0136
c0143 c0153
c0176 c0183
c0198 c0202
c0205

000010
(000196)

Paso 12 - Pallet dentro de elevador

W150.12

Paso 12 -
Pallet
dentro de
elevador

31.00

Ciclo
elevador -
Paso 1 -
Subir
rapido

MOV
(021)
&2
D410

[OP1]
[OP2]
Decodificador
secuencia
rodillos salida
<cD00410>
c0117 c0120
c0127 c0136
c0143 c0153
c0176 c0183
c0195 c0202
c0205
MOV
(021)
&1

[OP1]
[OP2]

17/11/2025 | 14 / 97 | PLC_Paletizadora.cxp
D420 | Decodificador salida

<cD00420>
c0124 c0208
c0212 c0226
c0229 c0235
c0240 c0245
c0250

000011
(000200)

Paso 25 - Alarma, pallet trabado

W151.09

paso 25 -
Alarma
pallet
trabado

610.10

Boton
reconocim
iento HMI

MOV
(021)
&4
D410

[OP1]
[OP2]
Decodificador
secuencia
rodillos salida
<cD00410>
c0117 c0120
c0127 c0136
c0143 c0153
c0176 c0183
c0195 c0198
c0205

000012
(000203)

Paso 26 - Alarma pallet trabado

W151.10

Paso 26 -
Alarma de
pallet
trabado

610.10

Boton
reconocim
iento HMI

MOV
(021)
&8
D410

[OP1]
[OP2]
Decodificador
secuencia
rodillos salida
<cD00410>
c0117 c0120
c0127 c0136
c0143 c0153
c0176 c0183
c0195 c0198
c0202

[Nombre de programa : General]; [Nombre de sección : Rodillo_salida]; Secuencia salida; P_On Indicador de siempre ON; MLPX (076) D420 #0 W250; [OP1] Decodificador salida <cD00420> c0124 c0199 c0212 c0226 c0229 c0235 c0240 c0245 c0250 [OP2] [OP3] <W250.01> a0209 <W250.02> a0213 <W250.03> a0236 <W250.04> a0241 <W250.05> a0246; Paso 1 - Espero; Paso 1 - espero; TIM; [OP1] Auxiliar; <T0238(bit)> a0211 [OP2]; Auxiliar; MOV (021) &2 D420; [OP1] [OP2] Decodificador salida <cD00420> c0124 c0199 c0208 c0226 c0229 c0235 c0240 c0245 c0250; Paso 2 - muevo hasta sensor; paso 2 -; OLD_X61 Acumulaci; ón pallets lleno; <T0242(bit)> a0218 [OP2]; SET; Q: 5.15 OLD_Y3 7; señal para máquina estrichadora; Se hizo resto; Q: 5.14 OLD_Y3 6; Señal para enfundadora - No enfundar; RSET; Se hizo resto <128.00> a0221

17/11/2025 | 15 / 97 | PLC_Paletizadora.cxp

OLD_X66 Señal de OK de enfundad ora no listo; MOV (021) &4 D420; [OP1] [OP2] Decodificador salida <cD00420> c0124 c0199 c0208 c0212 c0229 c0235 c0240 c0245 c0250; MOV (021) &3 D420; [OP1] [OP2] Decodificador salida <cD00420> c0124 c0199 c0208 c0212 c0226 c0235 c0240 c0245 c0250; OLD_X61 Acumulaci; ón pallets lleno; TIM; [OP1] Auxiliar; <T0243(bit)> a0234 [OP2]; Auxiliar; MOV (021) &0 D420; [OP1] [OP2] Decodificador salida <cD00420> c0124 c0199 c0208 c0212 c0226 c0229 c0240 c0245 c0250; Paso 3 - Espero reposición enfundad ora; [OP1] [OP2] Decodificador salida <cD00420> c0124 c0199 c0208 c0212 c0226 c0229 c0235 c0245 c0250; Enfundad ora NO habilitada - HMI; Paso 4 - Muevo hasta liberar sensor; paso 4; [OP1] Auxiliar liberacion; <T0233(bit)> a0244 [OP2]; Auxiliar liberacion; MOV (021) &5 D420; [OP1] [OP2] Decodificador salida

17/11/2025 | 16 / 97 | PLC_Paletizadora.cxp

Paso 3 - Espero repocición de enfundadora

17/11/2025 | 17 / 97 | PLC_Paletizadora.cxp

<cD00420>
c0124 c0199
c0208 c0212
c0226 c0229
c0235 c0240
c0250

000005
(000246)

Paso 5 - Espero fin de traslado enfundadora

W250.05

Paso 5 -
Espero
OK
enfundad
ora

129.00

Señal fin
transferen
cia
enfundad
ora

MOV
(021)
&0
D420

[OP1]
[OP2]
Decodificador
salida
<cD00420>
c0124 c0199
c0208 c0212
c0226 c0229
c0235 c0240
c0245
H0.05

Enfundad
ora NO
habilitada
- HMI

RSET

Q: 5.15
OLD_Y3
7

señal para
máquina
estrichadora

RSET

Q: 5.14
OLD_Y3
6

Señal para
enfundadora - No
enfundar

RSET

129.00

Señal fin
transferencia
enfundadora
<129.00>
a0247

[Nombre de programa : General]; [Nombre de sección : Elevador]; Ciclo elevador; Ciclo elevador - paso 0 - bajar lento; Ciclo elevador - Paso 1 - Subir rapido; Ciclo elevador - Paso 2 - subir rapido; Ciclo elevador - subir lento; Ciclo elevador - Paso 4 - Bajar lento; Ciclo elevador - Paso 5 - Subir lento; Ciclo elevador - paso 6 - bajar lento; Ciclo elevador - Paso 7 - bajar..lent o...rapido; Ciclo elevador - Paso 8 - Bajar rapido lento, Fin pallets; Cambio de pallets; OLD_X56 FT seguridad entrada elevador; OLD_X60 FT seguridad salida elevador; SET; Ciclo elevador - paso 0 - bajar lento <30.00> a0148 b0255 a0270; OLD_X46 elevador abajo; TIM; [OP1] Elevador abajo <T0002(bit)> a0149 a0271 a0363 [OP2]; Elevador abajo; Paso 12 - Pallet dentro de elevador; Ciclo elevador - Paso 1 - Subir rapido <31.00> a0197 b0256 a0275; RSET; Ciclo elevador - Paso 1; >= (325) D5004 D6000 [OP1] Auxiliar [OP2] Pulsos/tie mpo para parar rodillos; MOV (021) &0 D5008; [OP1] [OP2] Cantidad de pisos realizados <cD05008> c0301 c0306 c0311; MOV (021) &0 D5010; [OP1] [OP2] Cantidad de pisos realizados <cD05010> c0307; Ciclo elevador - Paso 2 - subir rapido <32.00> b0257 a0284

17/11/2025 | 18 / 97 | PLC_Paletizadora.cxp

Ciclo elevador - Paso 2 - subir rapido; OLD_X44 Elevador cambio velocidad subiendo; SET; Ciclo elevador - subir lento <33.00> b0258 a0291 a0374; RSET; Ciclo elevador - Paso 2 - subir rapido <32.00> b0257 a0284; OLD_X47 Fotocelula nivelación; TIM; [OP1] Demora de Nivelacion [OP2]; OLD_X43 Elevador arriba; Ciclo elevador - subir lento; Compuert a abierta; Ciclo elevador - Paso 4 - Bajar lento <34.00> b0259 a0297 a0312 a0375; P_On Indicador de siempre ON; [OP1] HMI - CANTIDAD DE FILAS POR PALLET [OP2] [OP3] Filas de pallets <cD01002> c0301 c0311; Ciclo elevador - Paso 4 - Bajar lento; [OP1] Tiempo libera fotocelula nivelacion <T0005(bit)> a0300 a0655 [OP2]; Tiempo libera fotocelula nivelacion; < (310) D5008 D1002 [OP1] Cantidad de pisos realizados [OP2] Filas de pallets; T. compuert a cerrada; MOV (021) &0 D5012; [OP1] [OP2] Auxiliar; MOV (021) &0 D5014

17/11/2025 | 19 / 97 | PLC_Paletizadora.cxp

17/11/2025 | 20 / 97 | PLC_Paletizadora.cxp

<cD05014>
c0331

@++
(590)
D5008

Cantidad de
pisos realizados
<cD05008>
c0280 c0301
c0311

@++
(590)
D5010

Cantidad de
pisos realizados
<cD05010>
c0281

SET

35.00

Ciclo elevador -
Paso 5 - Subir
lento
<35.00>
b0260 a0322
a0327 a0332
a0376

RSET

34.00

Ciclo elevador -
Paso 4 - Bajar
lento
<34.00>
b0259 a0297
a0312 a0375

000009
(000310)

Página 5 - OK

127.00 34.00

Ciclo
elevador -
Paso 4 -
Bajar
lento

SET

37.00

Ciclo elevador -
Paso 7 -
bajar..lento...rapid o

<37.00>
b0262 a0351
b0369 a0656
a1014

>=
(325)
D5008
D1002
[OP1]
Cantidad
de pisos
realizados
[OP2]
Filas de
pallets
RSET

34.00

Ciclo elevador -
Paso 4 - Bajar
lento
<34.00>
b0259 a0297
a0312 a0375

RSET

136.00

000010
(000316)

I: 1.13

OLD_X42
Deformaci
ón
compuert a

SET

202.00

Deformación
<202.00>
a0324 b0339
b0343

000011
(000318)

I: 1.13

OLD_X42
Deformaci

TIM

0042
#2

[OP1]
<T0042(bit)>
a0320

ón compuert a; RSET; Deformación <202.00> a0324 b0339 b0343; Contaddor; Ciclo elevador - Paso 5 - Subir lento; Elevador subir lento; Deformaci ón; P_0_2s Bit de pulso de reloj de 0.2 segundos; Auxiliar <cD05012> c0304; Contador; OLD_X47 Fotocelula nivelación; P_0_1s Bit de pulso de reloj de 0.1 segundos; Auxiliar <cD05014> c0305; Se realizo secuencia avance Bolsa 8 y 16; MOV (021) &0 D5016; [OP1] [OP2] Auxiliar; SET; Ciclo elevador - paso 6 - bajar lento <36.00> b0261 a0337 a0342 a0377; Ciclo elevador - Paso 5 - Subir lento <35.00> b0260 a0322 a0327 a0332 a0376; Ciclo elevador - paso 6 - bajar lento; Elevador bajar lento; Auxiliar <cD05016> c0334 c0346; TIM; [OP1] <T0021(bit)> a0345 [OP2]; Ciclo elevador - subir lento

17/11/2025 | 21 / 97 | PLC_Paletizadora.cxp

[OP1] Auxiliar; RSET; Ciclo elevador - paso 6 - bajar lento <36.00> b0261 a0337 a0342 a0377; Página 6 - OK; OLD_X45 Elevador cambio velocidad bajando; Ciclo elevador - Paso 7 - bajar..lent o...rapido; SET; Ciclo elevador - Paso 8 - Bajar rapido lento, Fin pallets <38.00> b0263 a0354 b0370 a0657; OLD_X46 elevador abajo; Ciclo elevador - Paso 7 - bajar..lento...rapid o; Ciclo elevador - Paso 8 - Bajar rapido lento, Fin pallets; P_Off Indicador de siempre OFF; OLD_X55 FT. Pallet en espera; Ciclo elevador - paso 0 - bajar lento <30.00> a0148 b0255 a0270; Elevador abajo; Ciclo elevador - Paso 1 - Subir rapido <31.00> a0197 b0256 a0275

17/11/2025 | 22 / 97 | PLC_Paletizadora.cxp

Cambio de pallets; Ciclo elevador - Paso 7 - bajar..lent o...rapido; Ciclo elevador - Paso 8 - Bajar rapido lento, Fin pallets; Automátic o activo; SET; Cambio de pallets <39.00> b0264 b0371 a0378; Ciclo elevador - subir lento; Ciclo elevador - Paso 7 - bajar..lento...rapid o <37.00> b0262 a0351 b0369 a0656 a1014; Ciclo elevador - Paso 4 - Bajar lento; Ciclo elevador - Paso 5 - Subir lento; RSET; Ciclo elevador - subir lento <33.00> b0258 a0291 a0374; Ciclo elevador - paso 6 - bajar lento; Ciclo elevador - Paso 4 - Bajar lento <34.00> b0259 a0297 a0312 a0375; Ciclo elevador - Paso 5 - Subir lento <35.00> b0260 a0322 a0327 a0332 a0376; Ciclo elevador - paso 6 - bajar lento <36.00> b0261 a0337 a0342 a0377

17/11/2025 | 23 / 97 | PLC_Paletizadora.cxp

17/11/2025 | 24 / 97 | PLC_Paletizadora.cxp

000000
(000386)

[Nombre de programa : General]

[Nombre de sección : Maquina_de_Film]

Encoder
Módulo CT021 > configurado en machine 10 Memoria inicial 2100 CIO

CF113

P_On
Indicador
de
siempre
ON

SET

Q: 2102.00

gate open

000001
(000388)

CF114

P_Off
Indicador
de
siempre
OFF

SET

Q: 2102.01

Gate Close

000002
(000390)

T0215

Tiempo
para
hacer 0

Q: 2102.03 Reset counter 1

000003
(000392)

CF113

P_On
Indicador
de
siempre
ON

Contador_1
Conversion_Encod
EN | ENO
Encoder I: 2122 | Encoder | D2000

Constan ⁺²,880000114

000004
(000394)

Habilitacion

I: 0.04

Pulsador_
abrir_sujet
ador
Llave de
habilitació
n

H0.00

Hab_FILM

Habilitación
proceso máquina
film
<H000.00>
a0103 b0105
b0398 a0400
b0533 b0541
b0546 b0552
a0554 b0557
a0559 a0565
b0567 b1508
a1510 b1514
a1516

000005
(000396)

Secuencia

CF113

P_On
Indicador
de
siempre
ON

MLPX
(076)
D100
#1000

W300

[OP1]
Pasos secuencia
Maquina Film
<cD00100>
c0399 c0402
c0415 c0418
c0423 c0433
c0440 c0448
c0455 c0462
c0471 c0482
c0489 c0495
c0507 c0517
c0524 c0531
c0534 c0537
c0540
[OP2]
[OP3]

Hab_FILM Habilitació n proceso máquina film; BSET (071) &0 D100 D101; [OP1] [OP2] Pasos secuencia Maquina Film <cD00100> c0397 c0402 c0415 c0418 c0423 c0433 c0440 c0448 c0455 c0462 c0471 c0482 c0489 c0495 c0507 c0517 c0524 c0531 c0534 c0537 c0540 [OP3] Paso anterior <cD00101> c0425 c0435 c0443 c0450 c0457 c0464 c0484 c0491 c0497 c0509 c0519 c0527; Paso 0 Inicio secuencia; Paso 0 maquina Film; MOV (021) &1 D100; [OP1] [OP2] Pasos secuencia Maquina Film <cD00100> c0397 c0399 c0415 c0418 c0423 c0433 c0440 c0448

17/11/2025 | 25 / 97 | PLC_Paletizadora.cxp

RSET; Cero carro OK <400.10> a0407 b0589; Paso 1 - Puesta a cero; Corte lamina <404.00> b0570 a0576; Cero carro OK; Corte_en_ reposo DT. Cortador en reposo; Aplicador _en_repo so DT. Aplicador en reposo; Sujeta FIlm (=1 sujetando); TIM; [OP1] Auxiliar <T0204(bit)> a0417 [OP2]; MOV (021) &22 D100; [OP1] [OP2] Pasos secuencia Maquina Film <cD00100> c0397 c0399 c0402 c0418 c0423 c0433 c0440 c0448 c0455 c0462 c0471 c0482 c0489 c0495 c0507 c0517 c0524 c0531 c0534 c0537 c0540; Auxiliar; MOV (021) &2 D100; [OP1] [OP2] Pasos secuencia Maquina Film <cD00100> c0397 c0399 c0402 c0415 c0423 c0433 c0440 c0448 c0455 c0462 c0471 c0482 c0489 c0495 c0507 c0517 c0524 c0531 c0534 c0537 c0540; [OP1] Tiempo falla <T0205(bit)> a0421 [OP2]; MOV

17/11/2025 | 26 / 97 | PLC_Paletizadora.cxp

Tiempo falla; P_Off Indicador de siempre OFF; Pasos secuencia; Maquina Film <cD00100> c0397 c0399 c0402 c0415 c0418 c0433 c0440 c0448 c0455 c0462 c0471 c0482 c0489 c0495 c0507 c0517 c0524 c0531 c0534 c0537 c0540; MOV (021) &1 D101; [OP1] [OP2] Paso anterior <cD00101> c0399 c0435 c0443 c0450 c0457 c0464 c0484 c0491 c0497 c0509 c0519 c0527; Paso 2 - espero condiciones; Paso 2 - Espera de pallets; Paso 10 - Espero OK de maq film; MOV (021) &5 D100; [OP1] [OP2] Pasos secuencia Maquina Film <cD00100> c0397 c0399 c0402 c0415 c0418 c0423 c0440 c0448 c0455 c0462 c0471 c0482 c0489 c0495 c0507 c0517 c0524 c0531 c0534 c0537 c0540; Film colocado; Pres_pall et Presencia de pallet en trasnporte (fotocelda ); MOV (021) &2 D101; [OP1] [OP2] Paso anterior <cD00101> c0399 c0425 c0443 c0450 c0457 c0464 c0484 c0491 c0497 c0509 c0519 c0527

17/11/2025 | 27 / 97 | PLC_Paletizadora.cxp

17/11/2025 | 28 / 97 | PLC_Paletizadora.cxp

000010
(000436)

Paso 5 - Tiempo

W300.05

Paso 5 -
Tiempo

TIM

0207
#4

[OP1] Auxiliar

<T0207(bit)>
a0439
[OP2]

T0207

Auxiliar

MOV
(021)
&6
D100

[OP1]
[OP2]
Pasos secuencia
Maquina Film
<cD00100>
c0397 c0399
c0402 c0415
c0418 c0423
c0433 c0448
c0455 c0462
c0471 c0482
c0489 c0495
c0507 c0517
c0524 c0531
c0534 c0537
c0540

RSET

408.00

Film colocado
<408.00>
b0429

MOV
(021)
&5
D101

[OP1]
[OP2]
Paso anterior
<cD00101>
c0399 c0425
c0435 c0450
c0457 c0464
c0484 c0491
c0497 c0509
c0519 c0527

000011
(000444)

Paso 6 - Cierre de pinzas

W300.06

Paso 6 -
Cierre de
pinzas

TIM

0208
#7

[OP1] Auxiliar

<T0208(bit)>
a0447
[OP2]

T0208

Auxiliar

MOV
(021)
&7
D100

[OP1]
[OP2]
Pasos secuencia
Maquina Film
<cD00100>
c0397 c0399
c0402 c0415
c0418 c0423
c0433 c0440
c0455 c0462
c0471 c0482
c0489 c0495
c0507 c0517
c0524 c0531
c0534 c0537
c0540

MOV
(021)
&6

[OP1]
[OP2]

17/11/2025 | 29 / 97 | PLC_Paletizadora.cxp
D101 | Paso anterior
<cD00101>
c0399 c0425
c0435 c0443
c0457 c0464
c0484 c0491
c0497 c0509
c0519 c0527

000012
(000451)

Paso 7 - Tiempo

W300.07

Paso 7 -
Tiempo

TIM

0209
#4

[OP1] Auxiliar

<T0209(bit)>
a0454
[OP2]

T0209

Auxiliar

MOV
(021)
&8
D100

[OP1]
[OP2]
Pasos secuencia
Maquina Film
<cD00100>
c0397 c0399
c0402 c0415
c0418 c0423
c0433 c0440
c0448 c0462
c0471 c0482
c0489 c0495
c0507 c0517
c0524 c0531
c0534 c0537
c0540

MOV
(021)
&7
D101

[OP1]
[OP2]
Paso anterior
<cD00101>
c0399 c0425
c0435 c0443
c0450 c0464
c0484 c0491
c0497 c0509
c0519 c0527

000013
(000458)

Paso 8 - Abre sujeta film

W300.08

Paso 8 - Abre

sujeta film

TIM

0210
#7

[OP1] Auxiliar

<T0210(bit)>
a0461
[OP2]

T0210

Auxiliar

MOV
(021)
&9
D100

[OP1]
[OP2]
Pasos secuencia
Maquina Film
<cD00100>
c0397 c0399
c0402 c0415
c0418 c0423
c0433 c0440
c0448 c0455
c0471 c0482
c0489 c0495
c0507 c0517
c0524 c0531

17/11/2025 | 30 / 97 | PLC_Paletizadora.cxp

c0534 c0537
c0540

MOV
(021)
&8
D101

[OP1]
[OP2]
Paso anterior
<cD00101>
c0399 c0425
c0435 c0443
c0450 c0457
c0484 c0491
c0497 c0509
c0519 c0527

000014
(000465)

Paso 9 - Primer Avance de carro

W300.09

Paso 9 -
Primer
avance de
carro

MOV
(021)
D2004
D2002

[OP1]
Largo HMI
<cD02004>
c0468 c0500
[OP2]
Destino en mm
de carro
<cD02002>
c0500 c0501
c0502 c0504
c0515 c0600
c0627

>=SL
(328)
D2000
D2004
[OP1]
Encoder
en
milimetros
[OP2]
Largo HMI

MOV
(021)
&10
D100

[OP1]
[OP2]
Pasos secuencia
Maquina Film
<cD00100>
c0397 c0399
c0402 c0415
c0418 c0423
c0433 c0440
c0448 c0455
c0462 c0482
c0489 c0495
c0507 c0517
c0524 c0531
c0534 c0537
c0540

I: 0.03

Aplicador _desplaza

do
DT. Aplicador

desplazad o

I: 0.01

Sensor_c
ontrol_bo
bina
DT.
control
bobina
aplicador

TIM

0211
#15

[OP1]
T auxiliar alarma
<T0211(bit)>
a0479
[OP2]

I: 0.01

Sensor_c
ontrol_bo
bina

TIM

0216
#15

[OP1]
T auxiliar alarma
<T0216(bit)>
a0480

17/11/2025 | 31 / 97 | PLC_Paletizadora.cxp

DT.
control
bobina
aplicador

[OP2]

T0211

T auxiliar
alarma

MOV
(021)
&20
D100

[OP1]
[OP2]
Pasos secuencia
Maquina Film
<cD00100>
c0397 c0399
c0402 c0415
c0418 c0423
c0433 c0440
c0448 c0455
c0462 c0471
c0489 c0495
c0507 c0517
c0524 c0531
c0534 c0537
c0540

T0216

T auxiliar
alarma
MOV
(021)
&9
D101

[OP1]
[OP2]
Paso anterior
<cD00101>
c0399 c0425
c0435 c0443
c0450 c0457
c0464 c0491
c0497 c0509
c0519 c0527

000015
(000485)

Paso 10 - Cierre sujetador

W300.10

Paso 10 -
Cierre
sujetador

TIM

0212
#5

[OP1] Auxiliar

<T0212(bit)>
a0488
[OP2]

T0212

Auxiliar

MOV
(021)
&11
D100

[OP1]
[OP2]
Pasos secuencia
Maquina Film
<cD00100>
c0397 c0399
c0402 c0415
c0418 c0423
c0433 c0440
c0448 c0455
c0462 c0471
c0482 c0495
c0507 c0517
c0524 c0531
c0534 c0537
c0540

MOV
(021)
&10
D101

[OP1]
[OP2]
Paso anterior
<cD00101>
c0399 c0425
c0435 c0443

17/11/2025 | 32 / 97 | PLC_Paletizadora.cxp

c0450 c0457
c0464 c0484
c0497 c0509
c0519 c0527

000016
(000492)

Paso 11 - Corte de lamina

W300.11

Paso 11 -
corte de
lamina

404.01

Retorno
de
cuchilla

MOV
(021)
&12
D100

[OP1]
[OP2]
Pasos secuencia
Maquina Film
<cD00100>
c0397 c0399
c0402 c0415
c0418 c0423
c0433 c0440
c0448 c0455
c0462 c0471
c0482 c0489
c0507 c0517
c0524 c0531
c0534 c0537
c0540

MOV
(021)
&11
D101

[OP1]
[OP2]
Paso anterior
<cD00101>
c0399 c0425
c0435 c0443
c0450 c0457
c0464 c0484
c0491 c0509
c0519 c0527

000017
(000498)

Paso 12 - Segundo avance Carro

W300.12

Paso 12 -
Segundo
avance

+
(400)
D2006
D2004
D2002

[OP1]
Segundo avance
HMI
[OP2]
Largo HMI
<cD02004>
c0467 c0468
[OP3]
Destino en mm
de carro
<cD02002>
c0467 c0501
c0502 c0504
c0515 c0600
c0627

>=
(325)
D2002
D2008
[OP1]
Destino
en mm de
carro
[OP2]
Maximo
distancia
film

MOV
(021)
D2008
D2002

[OP1]
Maximo distancia
film
<cD02008>
c0501
[OP2]
Destino en mm
de carro
<cD02002>
c0467 c0500
c0501 c0504
c0515 c0600
c0627

17/11/2025 | 33 / 97 | PLC_Paletizadora.cxp

>=
(325)
D2000
D2002
[OP1]
Encoder
en
milimetros
[OP2]
Destino
en mm de
carro

MOV
(021)
&13
D100

[OP1]
[OP2]
Pasos secuencia
Maquina Film
<cD00100>
c0397 c0399
c0402 c0415
c0418 c0423
c0433 c0440
c0448 c0455
c0462 c0471
c0482 c0489
c0495 c0517
c0524 c0531
c0534 c0537
c0540

I: 0.03

Aplicador _desplaza

do
DT. Aplicador

desplazad o

MOV
(021)
&12
D101

[OP1]
[OP2]
Paso anterior
<cD00101>
c0399 c0425
c0435 c0443
c0450 c0457
c0464 c0484
c0491 c0497
c0519 c0527

000018
(000510)

Paso 13 - Abre pinzas

W300.13

Paso 13 - Abrir

pinzas

I: 0.03

Aplicador _desplaza

do
DT. Aplicador

desplazad o

TIM

0213
#1

[OP1] Auxiliar

<T0213(bit)>
a0516
[OP2]

MOV
(021)
&1500
D2002

[OP1]
[OP2]
Destino en mm
de carro
<cD02002>
c0467 c0500
c0501 c0502
c0504 c0600
c0627
T0213

Auxiliar

MOV
(021)
&14
D100

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

17/11/2025 | 34 / 97 | PLC_Paletizadora.cxp

c0482 c0489
c0495 c0507
c0524 c0531
c0534 c0537
c0540

MOV
(021)
&13
D101

[OP1]
[OP2]
Paso anterior
<cD00101>
c0399 c0425
c0435 c0443
c0450 c0457
c0464 c0484
c0491 c0497
c0509 c0527

000019
(000520)

Paso 14 - Termino Maq film, hago cero

W300.14

Paso 14 -
termino
maq film,
cero

TIM

0229
#20

[OP1]
Auxiliar
<T0229(bit)>
a0523
[OP2]

T0229

Auxiliar

MOV
(021)
&1
D100

[OP1]
[OP2]
Pasos secuencia
Maquina Film
<cD00100>
c0397 c0399
c0402 c0415
c0418 c0423
c0433 c0440
c0448 c0455
c0462 c0471
c0482 c0489
c0495 c0507
c0517 c0531
c0534 c0537
c0540

SET

408.00

Film colocado
<408.00>
b0429

MOV
(021)
&14
D101

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

000020
(000528)

Paso 20 - Alarma No hay film

W301.04

Paso 20

610.10

Boton
reconocim
iento HMI

MOV
(021)
&1
D100

[OP1]
[OP2]
Pasos secuencia
Maquina Film
<cD00100>
c0397 c0399
c0402 c0415
c0418 c0423

17/11/2025 | 35 / 97 | PLC_Paletizadora.cxp

c0433 c0440
c0448 c0455
c0462 c0471
c0482 c0489
c0495 c0507
c0517 c0524
c0534 c0537
c0540

H0.00

Hab_FILM
Habilitació
n proceso
máquina
film

MOV
(021)
&1
D100

[OP1]
[OP2]
Pasos secuencia
Maquina Film
<cD00100>
c0397 c0399
c0402 c0415
c0418 c0423
c0433 c0440
c0448 c0455
c0462 c0471
c0482 c0489
c0495 c0507
c0517 c0524
c0531 c0537
c0540

000021
(000535)

Paso 22 - Aviso Falta sujetar film

W301.06

Paso 22

610.10

Boton
reconocim
iento HMI

MOV
(021)
&1
D100

[OP1]
[OP2]
Pasos secuencia
Maquina Film
<cD00100>
c0397 c0399
c0402 c0415
c0418 c0423
c0433 c0440
c0448 c0455
c0462 c0471
c0482 c0489
c0495 c0507
c0517 c0524
c0531 c0534
c0540

000022
(000538)

Paso 23 - Falla puesta a cero

W301.07

Paso 23

610.10

Boton
reconocim
iento HMI

MOV
(021)
&1
D100

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

000023
(000541)

Función sujeta film

Hab_FILM Habilitació n proceso máquina film; Pulsador_ cerrar_suj etador Pulsador Abrir/Cerr ar sujetador de Film; Sujeta FIlm (=1 sujetando); KEEP (011) 402.00; Sujeta FIlm (=1 sujetando) <402.00> a0411 b0414 b0543 a0548 b1509 a1515; Manual HMI Prensa; Función pinzas; Manual pinza HMI; KEEP (011) 403.00; Pinzas (=1 cierra); Paso 6 - Cierre de pinzas; Paso 1 - Puesta a cero; Paso 13 - Abrir pinzas; Función corte de lamina; Hab_FILM Habilitació; Paso 11 - corte de; Corte lamina; Retorno de; SET; Corte lamina <404.00> b0570 a0576

17/11/2025 | 36 / 97 | PLC_Paletizadora.cxp

n proceso máquina film; lamina; cuchilla; Hab_FILM Habilitació n proceso máquina film; Manual corte HMI; Paso 1 - Puesta a cero; RSET; Corte lamina <404.00> b0570 a0576; Retorno de cuchilla <404.01> a0494 b0571 a0582; Corte lamina; Corte_Acti vo DT. corte aplicador activado; TIM; [OP1] Auxiliar <T0202(bit)> a0579 [OP2]; Auxiliar; SET; Retorno de cuchilla; Corte_en_ reposo DT. Cortador en reposo; [OP1] Auxiliar <T0203(bit)> a0585 [OP2]; Manual corte HMI <610.06> a0568; Puesta a CERO carro; Cero carro OK; Paso 1 - carro hacia atrás; Paso 2 - caro hacia delante libera sensor; Paso 3 - Tiempo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

17/11/2025 | 37 / 97 | PLC_Paletizadora.cxp

Función puesta a cero; RSET; Cero carro OK <400.10> a0407 b0589; MOV (021) &0 D2002; [OP1] [OP2] Destino en mm de carro <cD02002> c0467 c0500 c0501 c0502 c0504 c0515 c0627; Paso 1 - carro hacia atrás; Aplicador _en_repo; so DT. Aplicador; en reposo; TIM; [OP1] Tiempo auxiliar <T0200(bit)> a0604 [OP2]; Tiempo auxiliar; Paso 1 - carro hacia atrás <400.01> b0591 a0601; SET; Paso 2 - caro hacia delante libera sensor <400.02> b0592 a0607; Paso 2 - caro hacia delante libera sensor; Paso 3 - Tiempo <400.03> b0593 a0611; Paso 3 - Tiempo; [OP1] Tiempo auxiliar <T0201(bit)> a0613 [OP2]; Paso 4 - Retrocede carro hasta sensor <400.04> b0594 a0616; Paso 4 - Retrocede carro hasta sensor

17/11/2025 | 38 / 97 | PLC_Paletizadora.cxp

SET; Paso 5 - reset encoder <400.05> b0595 a0620; Paso 5 - reset encoder; TIM; [OP1] Tiempo para hacer 0 <T0215(bit)> a0390 a0622 [OP2]; Tiempo para hacer 0; <=SL (318) D2000 &0 [OP1] Encoder en milimetros [OP2]; RSET; Cero carro OK <400.10> a0407 b0589; Función baja velocidad de carro; P_On Indicador de siempre ON; Velocidad_variador Funcion_baja_velo; ENO; Encoder Activa_b; Destino_ Activa_al; Distanci

17/11/2025 | 39 / 97 | PLC_Paletizadora.cxp

[Nombre de programa : General]; [Nombre de sección : Compuerta]; Compuerta; Comando cerrar compuert a; Comando abrir compuert a; Compuert a abierta; SET; Comando cerrar compuerta <50.00> b0629 a0635 a0638 a0965; OLD_X41 Compuert a cerrada; OLD_Y14 Abrir; compuert a; TIM; [OP1] T. compuerta cerrada <T0007(bit)> a0303 a0634 [OP2]; T. compuert a cerrada; Se realizo secuencia avance Bolsa 8 y 16; Comando abrir compuerta <51.00> b0630 a0642 a0645; RSET; OLD_Y12 EV. SALE PRENSA LATERAL; OLD_X40 Compuert a abierta; Marcha Automátic o; [OP1] Tiempo compuerta abierta <T0009(bit)> a0651 [OP2]; Tiempo compuert a abierta; Se realizo secuencia avance Bolsa 8 y 16 <69.00> a0333 a0639 b0971; Compuerta abierta <52.00> a0292 b0631 a0658; abierta

17/11/2025 | 40 / 97 | PLC_Paletizadora.cxp

17/11/2025 | 41 / 97 | PLC_Paletizadora.cxp

Tiempo
libera
fotocelula
nivelacion

Compuert
a abierta

52.00 <52.00> a0292 b0631 a0658

37.00

Ciclo
elevador -
Paso 7 -
bajar..lent
o...rapido
38.00

Ciclo
elevador -
Paso 8 -
Bajar
rapido
lento, Fin
pallets

[Nombre de programa : General]; [Nombre de sección : Carro_pala]; ############################# Secuencia Carro Pala; Paso 0 - Carro pala Esperand o bolsas; Paso 1 - carro pala avance; Paso 2 - carro pala avanza un poco mas (presiona bolsa); paso 3 - Carro pala retroceder; SET; Paso 0 - Carro pala Esperando bolsas <60.00> b0661 a0670 a0966; OLD_X63 Presion aire; OLD_X33 Pala arriba; OLD_Y5 Pala (válvula); TIM; [OP1] Tiempo espera pala arriba (filtro) [OP2]; OLD_X34 Carro pala en reposo; Bolsa 4, 8, 12 y 16 en posicion; RSET; Activación de barrera; Auxiliar sacar banderas de pedido <64.00> a0683 b0688; Bandera de realizar avance de carro pala <65.00> b0682 b0689 b0697 b0704 a0707 a0723 a0986 a0996 a1006 a1147 a1154 a1166 a1216 a1226 a1243 a1291 a1298 a1306 a1340 a1347 a1359; Paso 1 - carro pala avance <61.00> b0662 a0681 a0687 a0709 a0719 a0727 a0985 a1146 a1215 a1290 a1339; Fin Avance de carro pala (en pulsos); Bandera de realizar avance de carro pala; Auxiliar sacar banderas de pedido; Bandera para realizar bolsa 4,8,12 y 16

17/11/2025 | 42 / 97 | PLC_Paletizadora.cxp

OLD_X35 Carro Pala sobre compuert a; RSET; Bolsa 4, 8, 12 y 16 en posicion <55.00> a0673 b0972; Auxiliar sacar banderas de pedido <64.00> a0683 b0688; Paso 1 - carro pala avance; Auxiliar sacar banderas de pedido; Bandera de realiza; r avance de carro pala; SET; Bandera de realizar avance de carro pala <65.00> b0682 b0689 b0697 b0704 a0707 a0723 a0986 a0996 a1006 a1147 a1154 a1166 a1216 a1226 a1243 a1291 a1298 a1306 a1340 a1347 a1359; Paso 2 - carro pala avanza un poco mas (presiona bolsa) <62.00> b0663 a0696 a0711 a0720 a0995 a1153 a1225 a1297 a1346; Paso 1 - carro pala avance <61.00> b0662 a0681 a0687 a0709 a0719 a0727 a0985 a1146 a1215 a1290 a1339; Fin Avance; de carro pala (en pulsos); Paso 2 - carro pala avanza un poco mas (presiona bolsa)

17/11/2025 | 43 / 97 | PLC_Paletizadora.cxp

OLD_X36 Carro pala desplazad o; SET; paso 3 - Carro pala retroceder <63.00> b0664 a0703 a0714 a0721 a1005 a1165 a1242 a1305 a1358; RSET; Paso 2 - carro pala avanza un poco mas (presiona bolsa) <62.00> b0663 a0696 a0711 a0720 a0995 a1153 a1225 a1297 a1346; Fin Avance; de carro pala (en pulsos); paso 3 - Carro pala retroceder; Bandera de realiza; r avance de carro pala; Paso 0 - Carro pala Esperando bolsas <60.00> b0661 a0670 a0966; OLD_X34 Carro pala en reposo; MOV (021) &0 D5020; [OP1] [OP2] Pulsos carro pala <cD05020> c0716 c0717 c0724; Contador de pulsos carro pala; Paso 1 - carro pala avance; OLD_X0 Control contaje carro pala; Pulsos carro pala <cD05020> c0708 c0717 c0724; Paso 2 - carro pala avanza un poco mas (presiona bolsa); OLD_X35 Carro Pala sobre compuert a

17/11/2025 | 44 / 97 | PLC_Paletizadora.cxp

paso 3 - Carro pala retroceder; > (320) D5020 D1005 [OP1] Pulsos carro pala [OP2] Cantidad pulsos de Avance de carro; Fin Avance de; carro pala (en pulsos) <700.00> a0679 a0694 a0701; Paso 1 - carro pala avance; Pulsos de carro pala > Activación de velocidad carro pala; >L (321) D5020 D1003 [OP1] Pulsos carro pala [OP2] Activación de velocidad carro pala; Pulsos de carro; pala > Activación de velocidad carro pala <68.00> b0722; Paso 2 - carro pala avanza un poco mas (presiona bolsa); Bandera de realizar avance de carro pala; Seguridad arrastre carro pala; OLD_X37 Seguridad arraste carro pala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

17/11/2025 | 45 / 97 | PLC_Paletizadora.cxp

Se anula sensor 1.10 por pedido - Asistencia remota 30122022

17/11/2025 | 46 / 97 | PLC_Paletizadora.cxp

Contador; OLD_Y4 Rodillos Superiore s; P_0_1s Bit de pulso de reloj de 0.1 segundos; Auxiliar c7 <cD05022> c0759 c0773; (325) D5022 D1007 [OP1] Auxiliar c7; RSET; Auxiliar c8 (Accionamiento rodillos superiores) <cD05024> c0765 c0781; (325) D5024 D1008 [OP1] Auxiliar c8; (Acciona miento rodillos superiores ); Rodillos; superiores movio OK <86.00> a1143 a1183 a1209 a1277 a1285 a1331; Fin extracto; MOV (021) &0 D5002; [OP1] [OP2] Bolsas <cD05002> c0788 c0790 c0792; Fin extracto <155.00> a0784 a0939; Pulso para decodifica dor de movimient; Bolsas <cD05002> c0785 c0790 c0792

17/11/2025 | 47 / 97 | PLC_Paletizadora.cxp

17/11/2025 | 48 / 97 | PLC_Paletizadora.cxp

o rodillos
(bolsas)

000023
(000789)

Página 14 - OK

78.00 | MLPX (076)

Decodificador
tiempo de
movimiento
rodillos

D5002
#1000

| W0 | [OP1]
Bolsas
<cD05002>
c0785 c0788
c0792
[OP2]
[OP3]
<W000.01>
a0799 a1129
<W000.02>
a0808 a1132
<W000.03>
a0800 a1135
<W000.04>
a0809 a1138
a1145 a1171
<W000.05>
a0801 a1174
<W000.06>
a0810 a1177
a1185 a1212
a1221 a1235
<W000.07>
a0802 a1193
<W000.08>
a0811 a1196
a1204 a1211
a1232
<W000.09>
a0803 a1255
<W000.10>
a0812 a1258
a1261
<W000.11>
a0804 a1264
<W000.12>
a0813 a1267
a1270 a1288
a1336
<W000.13>
a0805 a1311
<W000.14>
a0814 a1314
a1317
<W000.15>
a0806 a1320

000024
(000791)

CF113

P_On
Indicador
de
siempre
ON
| MLPX (076) D5002
| #1000
| W20

[OP1]
Bolsas
<cD05002>
c0785 c0788
c0790
[OP2]
[OP3]

000025
(000793)
79.00 | 80.00 | <80.00>
b0754 a1130
a1133 a1136
a1172 a1175
a1186 a1194

17/11/2025 | 49 / 97 | PLC_Paletizadora.cxp

OLD_S2 Salida decodifica dor - Bolsa 2; Bolsas pares; OLD_S4 Salida decodifica dor - Bolsa 4; OLD_S6 Salida decodifica dor - Bolsa 6; OLD_S8 Salida decodifica dor - Bolsa 8; OLD_S10 Salida decodifica dor - Bolsa 10; OLD_S12 Salida decodifica dor - Bolsa 12; OLD_S14 Salida decodifica dor - Bolsa 14; OLD_S16 Salida decodifica dor - Bolsa 16; Pulso para decodifica dor de movimient o rodillos (bolsas); Accionar tope de giro (demora encendido ); Accionar tope de giro (demora apagado); Solicitud de accionami ento de tope de giro; MOV (021) &0 D5026; [OP1] [OP2] Pulsos tope de giro <cD05026> c0827

17/11/2025 | 50 / 97 | PLC_Paletizadora.cxp

SET; Accionar tope de giro (demora encendido) <91.00> b0819 a0824 a0828; Contador; Accionar tope de giro (demora encendido ); OLD_Y2 Cinta Programa da; P_0_2s Bit de pulso de reloj de 0.2 segundos; Pulsos tope de giro <cD05026> c0822; Solicitud de accionami ento de tope de giro; MOV (021) &0 D5028; [OP1] [OP2] Auxiliar C11; Accionar tope de giro (demora apagado) <92.00> b0820 a0833 a0837; RSET; Accionar tope de giro (demora apagado); Auxiliar C11 <cD05028> c0830 c0838; >= (325) D5028 &7 [OP1] Auxiliar; Accionar desplazad or; Solicitud de accionar valvula desplazad ora; MOV (021) &0 D5030; [OP1] [OP2] Demora de accion de desplazador <cD05030> c0847; Accionar desplazador <94.00> b0840 a0844

17/11/2025 | 51 / 97 | PLC_Paletizadora.cxp

Contador; Accionar desplazad or; OLD_Y2 Cinta Programa da; P_0_1s Bit de pulso de reloj de 0.1 segundos; Demora de accion de desplazador <cD05030> c0842; OLD_X64 Valvula desplazad ora afuera; OLD_X65 Valvula desplazad ora adentro; RSET; Solicitud de accionar valvula desplazadora <93.00> a0841; Accionar desplazador <94.00> b0840 a0844 a0848; M dosificació n; OLD_X30 FT dosificació n; SET; M dosificación <95.00> b0853 a0856; OLD_X31 FT contaje; FT vacia; OLD_X32 FT carros; TIM; [OP1] <T0013(bit)> a0865 [OP2]; PUENTE 3.15; OLD_Y1 Cinta aplanado superior (Paralaelo inferior); OLD_X27 FT acumulaci ón sacos; <= (315) D5032 D1014 [OP1] Contador cinta programa da [OP2] Pulsos a realizar cinta programa da; Página 16 - OK

17/11/2025 | 52 / 97 | PLC_Paletizadora.cxp

OLD_X27 FT acumulaci ón sacos; OLD_X30 FT dosificació n; Activación de Resto; OLD_Y1 Cinta aplanado superior (Paralaelo inferior); TIM; [OP1] <T0015(bit)> a0883 [OP2]; RSET; OLD_Y2 Cinta Programa da; OLD_X63 Presion aire; FT vacia; OLD_X31 FT contaje; PUENTE 3.15; SET; Entrada de bolsa; MOV (021) &0 D5032; [OP1] [OP2] Contador cinta programada <cD05032> c0871 c0914 c0915; Contador; P_0_1s Bit de pulso de reloj de 0.1 segundos; Contador cinta programada <cD05032> c0871 c0908 c0915; >= (325) D5032 D1014 [OP1] Contador cinta programa da [OP2] Pulsos a realizar cinta programa da; OLD_X64 Valvula desplazad ora afuera

17/11/2025 | 53 / 97 | PLC_Paletizadora.cxp

17/11/2025 | 54 / 97 | PLC_Paletizadora.cxp

RSET

102.00

<102.00>
b0875 a0911
a0917 b0968

000047
(000920)

156.00

Fin
extracto

MOV
(021)
&0
D5000

[OP1]
[OP2]
Contador bolsas
<cD05000>
c0924 c0926

RSET

156.00

Fin extracto
<156.00>
a0920

000048
(000923)

Contador bolsas de entrada

105.00 | @++ (590) D5000

Contador bolsas
<cD05000>
c0921 c0926

000049
(000925)
106.00 | MLPX (076)

Decodificador para
movimientos,
tiempos de pala
lateral, valvula
giradora

D5000
#1000

W100
[OP1]
Contador bolsas
<cD05000>
c0921 c0924
[OP2]
[OP3]
<W100.01>
a1027
<W100.02>
a1038
<W100.03>
a1041
<W100.04>
a1050
<W100.05>
a1053
<W100.06>
a1058
<W100.07>
a1066
<W100.08>
a1076
<W100.09>
a1084
<W100.10>
a1094
<W100.11>
a1097
<W100.12>
a1107
<W100.13>
a1112
<W100.14>
a1117
<W100.15>
a1120

000050
(000927)
107.00 | 108.00 | Entrada de bolsa
<108.00>
b0902 a1028
a1039 a1042
a1051 a1054
a1059 a1067

17/11/2025 | 55 / 97 | PLC_Paletizadora.cxp

[Nombre de programa : General]; [Nombre de sección : Resto]; OLD_X27 FT acumulaci ón sacos; TIM; [OP1] <T0016(bit)> a0944 a0947 [OP2]; [OP1] <T0017(bit)> b0945 [OP2]; Secuencia resto - Paso 1; Secuencia resto - Paso 2; Secuencia resto - Paso 3; Secuencia resto - Paso 4; Secuencia resto - Paso 5; Secuencia resto - Paso 6; Llave Man Aut HMI (1=AUT); Resto; SET; Activación de Resto <120.00> b0880 b0887; Secuencia resto - Paso 1 <121.00> a0936 b0950 a0961 a0964; Se hizo resto <128.00> a0221; MOV; Comando cerrar compuert a; Paso 0 - Carro pala Esperand o bolsas; [OP1] <T0018(bit)> a0970 [OP2]; Se realizo secuencia avance Bolsa 8 y 16; Bolsa 4, 8, 12 y 16 en posicion; Secuencia resto - Paso 2 <122.00> b0951 a0975; RSET; OLD_Y4 Rodillos Superiore s; [OP1] <T0019(bit)> a0978 [OP2]; Bandera para; realizar bolsa

17/11/2025 | 56 / 97 | PLC_Paletizadora.cxp

17/11/2025 | 57 / 97 | PLC_Paletizadora.cxp
54.00 | 4,8,12 y 16

SET

55.00 | Bolsa 4, 8, 12 y 16 en posicion

<55.00>
a0673 b0972

SET

123.00 | Secuencia resto - Paso 3

<123.00>
b0952 a0984

RSET

122.00 | Secuencia resto - Paso 2

<122.00>
b0951 a0975

000006
(000984)

123.00

Secuencia
resto -
Paso 3

61.00

Paso 1 -
carro pala
avance

65.00

Bandera
de realiza

r
avance de
carro pala

SET

155.00 | Fin extracto
<155.00>
a0784 a0939

SET

156.00

Fin extracto
<156.00>
a0920

MOV
(021)
&5
D1003

[OP1]
[OP2] Activación de

velocidad carro
pala
<cD01003>
c0724 c0997
c1008 c1148
c1156 c1167
c1217 c1228
c1245 c1292
c1299 c1307
c1341 c1349
c1360

MOV
(021)
&40
D1005

[OP1]
[OP2]
Cantidad pulsos
de Avance de
carro
<cD01005>
c0717 c0998
c1009 c1149
c1157 c1159
c1168 c1218
c1229 c1233
c1236 c1246
c1293 c1300
c1308 c1342
c1350 c1352
c1361

RSET

65.00

Bandera de
realizar avance
de carro pala
<65.00>
b0682 b0689
b0697 b0704
a0707 a0723
a0986 a0996
a1006 a1147
a1154 a1166
a1216 a1226

17/11/2025 | 58 / 97 | PLC_Paletizadora.cxp

a1243 a1291
a1298 a1306
a1340 a1347
a1359

SET

124.00

Secuencia resto -
Paso 4
<124.00>
b0953 a0994

RSET

123.00

Secuencia resto -
Paso 3
<123.00>
b0952 a0984

000007
(000994)

124.00

Secuencia
resto -
Paso 4

62.00

Paso 2 -
carro pala
avanza un
poco mas
(presiona
bolsa)

65.00

Bandera
de realiza

r
avance de
carro pala

MOV
(021)
&11
D1003

[OP1]
[OP2] Activación de

velocidad carro
pala
<cD01003>
c0724 c0989
c1008 c1148
c1156 c1167
c1217 c1228
c1245 c1292
c1299 c1307
c1341 c1349
c1360

MOV
(021)
&26
D1005

[OP1]
[OP2]
Cantidad pulsos
de Avance de
carro
<cD01005>
c0717 c0990
c1009 c1149
c1157 c1159
c1168 c1218
c1229 c1233
c1236 c1246
c1293 c1300
c1308 c1342
c1350 c1352
c1361

RSET

65.00

Bandera de
realizar avance
de carro pala
<65.00>
b0682 b0689
b0697 b0704
a0707 a0723
a0986 a0996
a1006 a1147
a1154 a1166
a1216 a1226
a1243 a1291
a1298 a1306
a1340 a1347
a1359
SET

127.00

<127.00>
b0302 a0310

RSET

120.00

Activación de
Resto
<120.00>
b0880 b0887

17/11/2025 | 59 / 97 | PLC_Paletizadora.cxp

SET

125.00

Secuencia resto
- Paso 5
<125.00>
b0954 a1004

RSET

124.00

Secuencia resto -
Paso 4
<124.00>
b0953 a0994

000008
(001004)

125.00

Secuencia
resto -
Paso 5

63.00

paso 3 -
Carro pala
retroceder

65.00

Bandera
de realiza

r
avance de
carro pala

SET

69.00

Se realizo
secuencia
avance Bolsa 8 y
16
<69.00>
a0333 a0639
b0971

MOV
(021)
&24
D1003

[OP1]
[OP2] Activación de

velocidad carro
pala
<cD01003>
c0724 c0989
c0997 c1148
c1156 c1167
c1217 c1228
c1245 c1292
c1299 c1307
c1341 c1349
c1360

MOV
(021)
&50
D1005

[OP1]
[OP2]
Cantidad pulsos
de Avance de
carro
<cD01005>
c0717 c0990
c0998 c1149
c1157 c1159
c1168 c1218
c1229 c1233
c1236 c1246
c1293 c1300
c1308 c1342
c1350 c1352
c1361

RSET

65.00

Bandera de
realizar avance
de carro pala
<65.00>
b0682 b0689
b0697 b0704
a0707 a0723
a0986 a0996
a1006 a1147
a1154 a1166
a1216 a1226
a1243 a1291
a1298 a1306
a1340 a1347
a1359
SET

126.00

Secuencia resto -
Paso 6
<126.00>
b0955 a1013

17/11/2025 | 60 / 97 | PLC_Paletizadora.cxp

RSET

125.00

Secuencia resto
- Paso 5
<125.00>
b0954 a1004

000009
(001013)

126.00

Secuencia
resto -
Paso 6

37.00

Ciclo
elevador -
Paso 7 -
bajar..lent
o...rapido

RSET

127.00

<127.00>
b0302 a0310

RSET

126.00

Secuencia resto -
Paso 6
<126.00>
b0955 a1013

000010
(001017)

600.10

Boton
reset HMI

RSET

120.00

Activación de
Resto
<120.00>
b0880 b0887

RSET

121.00

Secuencia resto -
Paso 1
<121.00>
a0936 b0950
a0961 a0964

RSET

122.00

Secuencia resto -
Paso 2
<122.00>
b0951 a0975

RSET

123.00

Secuencia resto -
Paso 3
<123.00>
b0952 a0984

RSET

124.00

Secuencia resto -
Paso 4
<124.00>
b0953 a0994

RSET

125.00

Secuencia resto
- Paso 5
<125.00>
b0954 a1004

RSET

126.00

Secuencia resto -
Paso 6
<126.00>
b0955 a1013

RSET

127.00

<127.00>
b0302 a0310

[Nombre de programa : General]; [Nombre de sección : Secuencia_entrada_bolsa]; OLD_S10 1 Salida decodifica dor 2 Entrada de bolsa; Entrada de bolsa; Habilitacio n de Euro Pallet; RSET; Solicitud de accionamiento de tope de giro <90.00> a0821 b0829; SET; Solicitud de accionar valvula desplazadora <93.00> a0841; MOV (021) &6 D1014; [OP1] [OP2] Pulsos a realizar cinta programada <cD01014> c0871 c0915 c1036 c1040 c1045 c1049 c1052 c1055 c1062 c1065 c1071 c1075 c1080 c1083 c1088 c1092 c1096 c1102 c1106 c1109 c1114 c1119 c1122 c1127; [OP1] [OP2] Pulsos a realizar cinta programada <cD01014> c0871 c0915 c1033 c1040 c1045 c1049 c1052 c1055 c1062 c1065 c1071 c1075 c1080 c1083 c1088 c1092 c1096 c1102 c1106 c1109 c1114 c1119 c1122 c1127; OLD_S10 2 Salida decodifica dor 2; MOV (021) &5 D1014; [OP1] [OP2] Pulsos a realizar cinta programada <cD01014> c0871 c0915

17/11/2025 | 61 / 97 | PLC_Paletizadora.cxp

Decodificador entradas de bolsas (comando de giro de bolsa y desplazador)

OLD_S10 3; Salida decodifica dor 2; Entrada de bolsa; Habilitacio n de Euro Pallet; MOV (021) &2 D1014; [OP1] [OP2] Pulsos a realizar cinta programada <cD01014> c0871 c0915 c1033 c1036 c1040 c1049 c1052 c1055 c1062 c1065 c1071 c1075 c1080 c1083 c1088 c1092 c1096 c1102 c1106 c1109 c1114 c1119 c1122 c1127; SET; Solicitud de accionamiento de tope de giro <90.00> a0821 b0829; [OP1] [OP2] Pulsos a realizar cinta programada <cD01014> c0871 c0915 c1033 c1036 c1040 c1045 c1052 c1055 c1062 c1065 c1071 c1075 c1080 c1083 c1088 c1092 c1096 c1102 c1106 c1109 c1114 c1119 c1122 c1127; OLD_S10 4; MOV (021) &12 D1014; [OP1] [OP2] Pulsos a realizar cinta programada <cD01014> c0871 c0915 c1033 c1036 c1040 c1045 c1049 c1055 c1062 c1065 c1071 c1075 c1080 c1083 c1088 c1092 c1096 c1102 c1106 c1109

17/11/2025 | 62 / 97 | PLC_Paletizadora.cxp

17/11/2025 | 63 / 97 | PLC_Paletizadora.cxp

c1114 c1119
c1122 c1127

000004
(001053)

W100.05

OLD_S10 5

Salida
decodifica
dor 2

108.00

Entrada
de bolsa

MOV
(021)
&6
D1014

[OP1]
[OP2]
Pulsos a realizar
cinta programada
<cD01014>
c0871 c0915
c1033 c1036
c1040 c1045
c1049 c1052
c1062 c1065
c1071 c1075
c1080 c1083
c1088 c1092
c1096 c1102
c1106 c1109
c1114 c1119
c1122 c1127

H10.00

Habilitacio
n de Euro
Pallet

RSET

90.00

Solicitud de
accionamiento de
tope de giro
<90.00>
a0821 b0829

000005
(001058)

W100.06

OLD_S10 6

Salida
decodifica
dor 2

108.00

Entrada
de bolsa

H10.00

Habilitacio
n de Euro
Pallet

MOV
(021)
&9
D1014

[OP1]
[OP2]
Pulsos a realizar
cinta programada
<cD01014>
c0871 c0915
c1033 c1036
c1040 c1045
c1049 c1052
c1055 c1065
c1071 c1075
c1080 c1083
c1088 c1092
c1096 c1102
c1106 c1109
c1114 c1119
c1122 c1127

H10.00

Habilitacio
n de Euro
Pallet

MOV
(021)
&16
D1014

[OP1]
[OP2]
Pulsos a realizar
cinta programada
<cD01014>
c0871 c0915
c1033 c1036
c1040 c1045
c1049 c1052
c1055 c1062
c1071 c1075
c1080 c1083
c1088 c1092
c1096 c1102
c1106 c1109
c1114 c1119
c1122 c1127

000006
(001066)

W100.07

OLD_S10 7

Salida
decodifica
dor 2

108.00

Entrada
de bolsa

H10.00

Habilitacio
n de Euro
Pallet

RSET

90.00

Solicitud de
accionamiento de
tope de giro
<90.00>
a0821 b0829

MOV (021) &6 D1014; [OP1] [OP2] Pulsos a realizar cinta programada <cD01014> c0871 c0915 c1033 c1036 c1040 c1045 c1049 c1052 c1055 c1062 c1065 c1075 c1080 c1083 c1088 c1092 c1096 c1102 c1106 c1109 c1114 c1119 c1122 c1127; SET; Solicitud de accionar valvula desplazadora <93.00> a0841; Habilitacio n de Euro Pallet; [OP1] [OP2] Pulsos a realizar cinta programada <cD01014> c0871 c0915 c1033 c1036 c1040 c1045 c1049 c1052 c1055 c1062 c1065 c1071 c1080 c1083 c1088 c1092 c1096 c1102 c1106 c1109 c1114 c1119 c1122 c1127; OLD_S10 8; Salida decodifica dor 2; Entrada de bolsa; MOV (021) &14 D1014; [OP1] [OP2] Pulsos a realizar cinta programada <cD01014> c0871 c0915 c1033 c1036 c1040 c1045 c1049 c1052 c1055 c1062 c1065 c1071 c1075 c1083 c1088 c1092 c1096 c1102 c1106 c1109 c1114 c1119 c1122 c1127; MOV (021) &16 D1014; [OP1] [OP2] Pulsos a realizar cinta programada <cD01014> c0871 c0915 c1033 c1036 c1040 c1045 c1049 c1052

17/11/2025 | 64 / 97 | PLC_Paletizadora.cxp

OLD_S10 9; Salida decodifica dor 2; Entrada de bolsa; Habilitacio n de Euro Pallet; MOV (021) &2 D1014; [OP1] [OP2] Pulsos a realizar cinta programada <cD01014> c0871 c0915 c1033 c1036 c1040 c1045 c1049 c1052 c1055 c1062 c1065 c1071 c1075 c1080 c1083 c1092 c1096 c1102 c1106 c1109 c1114 c1119 c1122 c1127; SET; Solicitud de accionamiento de tope de giro <90.00> a0821 b0829; [OP1] [OP2] Pulsos a realizar cinta programada <cD01014> c0871 c0915 c1033 c1036 c1040 c1045 c1049 c1052 c1055 c1062 c1065 c1071 c1075 c1080 c1083 c1088 c1096 c1102 c1106 c1109 c1114 c1119 c1122 c1127; OLD_S11 0; MOV (021) &9 D1014; [OP1] [OP2] Pulsos a realizar cinta programada <cD01014> c0871 c0915 c1033 c1036 c1040 c1045 c1049 c1052 c1055 c1062 c1065 c1071 c1075 c1080

17/11/2025 | 65 / 97 | PLC_Paletizadora.cxp

OLD_S11 1; Salida decodifica dor 2; Entrada de bolsa; Habilitacio n de Euro Pallet; RSET; Solicitud de accionamiento de tope de giro <90.00> a0821 b0829; MOV (021) &6 D1014; [OP1] [OP2] Pulsos a realizar cinta programada <cD01014> c0871 c0915 c1033 c1036 c1040 c1045 c1049 c1052 c1055 c1062 c1065 c1071 c1075 c1080 c1083 c1088 c1092 c1096 c1106 c1109 c1114 c1119 c1122 c1127; SET; Solicitud de accionar valvula desplazadora <93.00> a0841; [OP1] [OP2] Pulsos a realizar cinta programada <cD01014> c0871 c0915 c1033 c1036 c1040 c1045 c1049 c1052 c1055 c1062 c1065 c1071 c1075 c1080 c1083 c1088 c1092 c1096 c1102 c1109 c1114 c1119 c1122 c1127; OLD_S11 2; MOV (021) &16 D1014; [OP1] [OP2] Pulsos a realizar cinta programada <cD01014> c0871 c0915 c1033 c1036 c1040 c1045 c1049 c1052 c1055 c1062 c1065 c1071 c1075 c1080 c1083 c1088 c1092 c1096

17/11/2025 | 66 / 97 | PLC_Paletizadora.cxp

17/11/2025 | 67 / 97 | PLC_Paletizadora.cxp

c1102 c1106
c1114 c1119
c1122 c1127

H10.00

Habilitacio
n de Euro
Pallet

SET

156.00

Fin extracto
<156.00>
a0920

000012
(001112)

W100.13

OLD_S11 3

Salida
decodifica
dor 2

108.00

Entrada
de bolsa

MOV
(021)
&6
D1014

[OP1]
[OP2]
Pulsos a realizar
cinta programada
<cD01014>
c0871 c0915
c1033 c1036
c1040 c1045
c1049 c1052
c1055 c1062
c1065 c1071
c1075 c1080
c1083 c1088
c1092 c1096
c1102 c1106
c1109 c1119
c1122 c1127

RSET

90.00

Solicitud de
accionamiento de
tope de giro
<90.00>
a0821 b0829

SET

93.00

Solicitud de
accionar valvula
desplazadora
<93.00>
a0841

000013
(001117)

W100.14

OLD_S11 4

Salida
decodifica
dor 2

108.00

Entrada
de bolsa

MOV
(021)
&5
D1014

[OP1]
[OP2]
Pulsos a realizar
cinta programada
<cD01014>
c0871 c0915
c1033 c1036
c1040 c1045
c1049 c1052
c1055 c1062
c1065 c1071
c1075 c1080
c1083 c1088
c1092 c1096
c1102 c1106
c1109 c1114
c1122 c1127

000014
(001120)

W100.15

OLD_S11 5

Salida
decodifica
dor 2

108.00

Entrada
de bolsa

MOV
(021)
&2
D1014

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

17/11/2025 | 68 / 97 | PLC_Paletizadora.cxp

c1083 c1088
c1092 c1096
c1102 c1106
c1109 c1114
c1119 c1127

SET

90.00

Solicitud de
accionamiento de
tope de giro
<90.00>
a0821 b0829

000015
(001124)

W101.00

OLD_S11
6
Salida
decodifica
dor 2

108.00

Entrada
de bolsa

SET

156.00

Fin extracto
<156.00>
a0920

MOV
(021)
&20
D1014

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

[Nombre de programa : General]; [Nombre de sección : Secuencia_rodillos_Pala]; ########################### Decodificador rodillos; OLD_S1 Salida decodifica dor - Bolsa 1; MOV; [OP1] Bolsa 1 [OP2]; OLD_S2 Salida decodifica dor - Bolsa 2; [OP1] Bolsa 2 [OP2] <cD01008> c0781 c1173 c1189 c1192 c1200 c1203 c1260 c1269 c1319 c1324; OLD_S3 Salida decodifica dor; [OP1] Bolsa 3 [OP2]; Muevo Pala en modo normal y Euro; OLD_S4 Salida decodifica dor - Bolsa 4; Pulso bolsa par entrando; SET; Bandera para realizar bolsa 4,8,12 y 16; Rodillos superiores movio OK; Bolsa 4, 8, 12 y 16 en posicion <55.00> a0673 b0972; Paso 1 - carro pala avance; Bandera de realizar avance de carro pala; MOVL (498) &5 D1003; [OP1] [OP2] Activación de velocidad carro pala <cD01003> c0724 c0989 c0997 c1008 c1156 c1167 c1217 c1228 c1245 c1292 c1299 c1307 c1341 c1349 c1360

17/11/2025 | 69 / 97 | PLC_Paletizadora.cxp

(movimiento de rodillos y accionamiento de carro pala)

En modo normal: 8 bolsas por extractor, la pala se mueve dos veces

En modo Euro: 6 bolsas por extracto, la pala se mueve 1 vez

17/11/2025 | 70 / 97 | PLC_Paletizadora.cxp

MOVL
(498)
&40
D1005

[OP1]
[OP2]
Cantidad pulsos
de Avance de
carro
<cD01005>
c0717 c0990
c0998 c1009
c1157 c1159
c1168 c1218
c1229 c1233
c1236 c1246
c1293 c1300
c1308 c1342
c1350 c1352
c1361

RSET

65.00

Bandera de
realizar avance
de carro pala
<65.00>
b0682 b0689
b0697 b0704
a0707 a0723
a0986 a0996
a1006 a1147
a1154 a1166
a1216 a1226
a1243 a1291
a1298 a1306
a1340 a1347
a1359
SET

138.00

Carro pala fin
avanse
<138.00>
a1152

000005
(001152)

138.00

Carro pala
fin avanse

62.00

Paso 2 -
carro pala
avanza un
poco mas
(presiona
bolsa)

65.00

Bandera
de realiza

r
avance de
carro pala

MOV
(021)
&35
D1003

[OP1]
[OP2] Activación de

velocidad carro
pala
<cD01003>
c0724 c0989
c0997 c1008
c1148 c1167
c1217 c1228
c1245 c1292
c1299 c1307
c1341 c1349
c1360

MOV
(021)
&48
D1005

[OP1]
[OP2]
Cantidad pulsos
de Avance de
carro
<cD01005>
c0717 c0990
c0998 c1009
c1149 c1159
c1168 c1218
c1229 c1233
c1236 c1246
c1293 c1300
c1308 c1342
c1350 c1352
c1361

Habilitacio n de Euro Pallet; MOV (021) &38 D1005; [OP1] [OP2] Cantidad pulsos de Avance de carro <cD01005> c0717 c0990 c0998 c1009 c1149 c1157 c1168 c1218 c1229 c1233 c1236 c1246 c1293 c1300 c1308 c1342 c1350 c1352 c1361; RSET; Bandera de realizar avance de carro pala <65.00> b0682 b0689 b0697 b0704 a0707 a0723 a0986 a0996 a1006 a1147 a1154 a1166 a1216 a1226 a1243 a1291 a1298 a1306 a1340 a1347 a1359; SET; Carro pala - segundo avance <139.00> a1164; Carro pala fin avanse <138.00> a1152; Carro pala - segundo avance; paso 3 - Carro pala retroceder; Bandera de realizar avance de carro pala; MOV (021) &25 D1003; [OP1] [OP2] Activación de velocidad carro pala <cD01003> c0724 c0989 c0997 c1008 c1148 c1156 c1217 c1228 c1245 c1292 c1299 c1307 c1341 c1349 c1360; MOV (021) &70 D1005; [OP1] [OP2] Cantidad pulsos de Avance de carro <cD01005> c0717 c0990 c0998 c1009 c1149 c1157 c1159 c1218 c1229 c1233 c1236 c1246

17/11/2025 | 71 / 97 | PLC_Paletizadora.cxp

RSET; Bandera de realizar avance de carro pala <65.00> b0682 b0689 b0697 b0704 a0707 a0723 a0986 a0996 a1006 a1147 a1154 a1166 a1216 a1226 a1243 a1291 a1298 a1306 a1340 a1347 a1359; Carro pala - segundo avance <139.00> a1164; OLD_S4 Salida decodifica dor - Bolsa 4; MOV; Original valor &8; [OP1] Bolsa 4 [OP2] <cD01008> c0781 c1134 c1189 c1192 c1200 c1203 c1260 c1269 c1319 c1324; OLD_S5 Salida decodifica dor - Bolsa 5; OLD_S6 Salida decodifica dor - Bolsa 6; Habilitacio n de Euro Pallet; Pulso bolsa par entrando; SET; Bandera para realizar bolsa 4,8,12 y 16; Rodillos superiores movio OK; Bolsa 4, 8, 12 y 16 en posicion <55.00> a0673 b0972; MOV (021) D505 D1008; [OP1] Bolsa 6 [OP2] <cD01008> c0781 c1134 c1173 c1192 c1200 c1203 c1260 c1269 c1319 c1324; MOV (021) &2 D1008

17/11/2025 | 72 / 97 | PLC_Paletizadora.cxp

OLD_S7 Salida decodifica dor - Bolsa 7; MOV; OLD_S8 Salida decodifica dor - Bolsa 8; Habilitacio n de Euro Pallet; MOV (021); Original valor &8; [OP1] Bolsa 8 [OP2] <cD01008> c0781 c1134 c1173 c1189 c1192 c1203 c1260 c1269 c1319 c1324; Muevo pala en Modo normal y Euro; Pulso bolsa par entrando; SET; Bandera para realizar bolsa 4,8,12 y 16; Rodillos superiores movio OK; Bolsa 4, 8, 12 y 16 en posicion <55.00> a0673 b0972; Muevo pala en modo Normal y modo Euro; Paso 1 - carro pala avance; Bandera de realiza; r avance de carro pala; MOV (021) &5 D1003; [OP1] [OP2] Activación de; velocidad carro pala <cD01003> c0724 c0989 c0997 c1008 c1148 c1156 c1167 c1228 c1245 c1292 c1299 c1307 c1341 c1349 c1360; OLD_S6 Salida; Habilitacio n de Euro

17/11/2025 | 73 / 97 | PLC_Paletizadora.cxp
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

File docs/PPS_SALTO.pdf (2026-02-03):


Informe de Práctica Profesional Supervisada

### Mejora del sistema de prensado en paletizado

Tutor/a:
Ing. LUKASZEWICZ, Cristian

Alumno/a:
Alejo Daniel Salto

Firma del Tutor institucional:

Facultad de Ingeniería
Universidad Nacional de Lomas de Zamora

## Índice

### Reservado a la Facultad para evaluación

### Lugar en donde he realizado la PPS

La Práctica Profesional Supervisada (PPS) la realicé en la empresa Weber – Saint-Gobain, en la planta ubicada en el partido de Bosques, provincia de Buenos Aires. Esta fábrica cuenta con tres líneas de producción orientadas a la elaboración de productos para la construcción, con un alto nivel de automatización en gran parte de sus etapas. Dentro de ese contexto, el trabajo se enfocó en una paletizadora automática, uno de los equipos más antiguos del sector, equipada con una prensa lateral utilizada durante el armado del pallet. El sistema de control del equipo estuvo basado en un PLC Omron CJ2M y una interfaz HMI Omron NS5. Durante la práctica me vinculé principalmente con el departamento de mantenimiento, donde relevé información técnica, consulté documentación y analicé el funcionamiento del equipo. También interactué con operarios de producción para comprender el uso habitual de la paletizadora, el comportamiento esperado por el operador y las condiciones reales de operación asociadas a los distintos productos fabricados.
La planta me brindó acceso a documentación técnica, planos eléctricos y al programa Ladder existente, además de las herramientas de software utilizadas en automatización industrial (CX-Programmer y CX-Designer). Esta información me permitió estudiar la secuencia de operación, identificar señales relevantes, evaluar restricciones del proceso y diseñar una mejora compatible con la lógica existente, sin interferir con la producción.
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

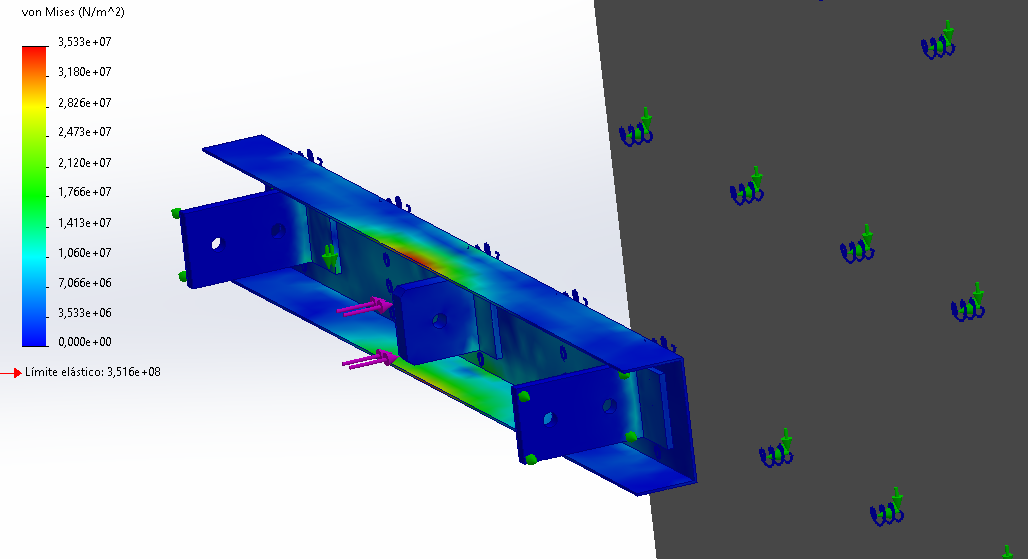
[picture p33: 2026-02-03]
imagenes/CEM_03_vonMises.png

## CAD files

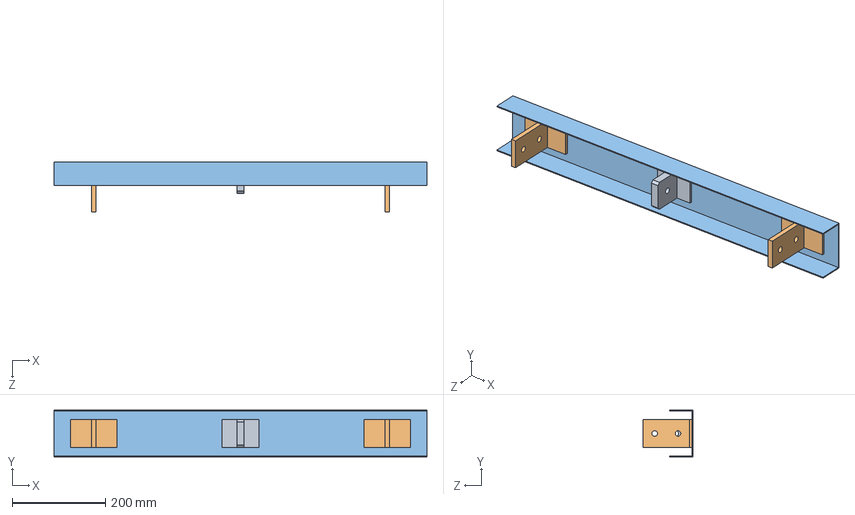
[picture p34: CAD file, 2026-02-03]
mecanica/Prensa.SLDASM
800.0 x 100.0 x 107.0 mm
Placa
Orejetas x 2
Horquilla

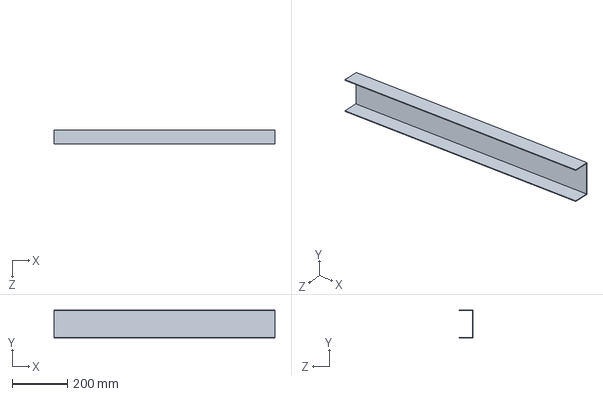
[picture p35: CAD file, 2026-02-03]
mecanica/Placa.SLDPRT
800.0 x 100.0 x 50.0 mm

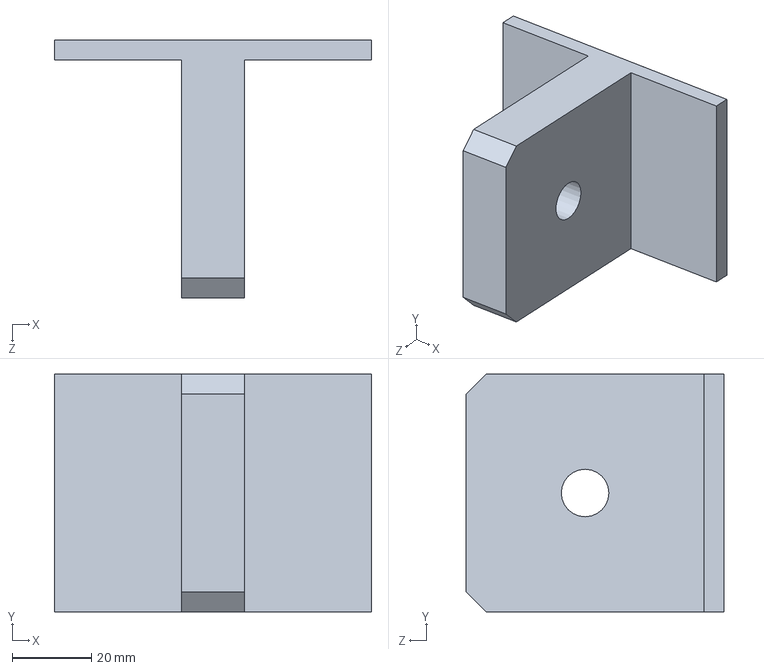
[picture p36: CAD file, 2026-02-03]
mecanica/Horquilla.SLDPRT
80.0 x 60.0 x 65.0 mm

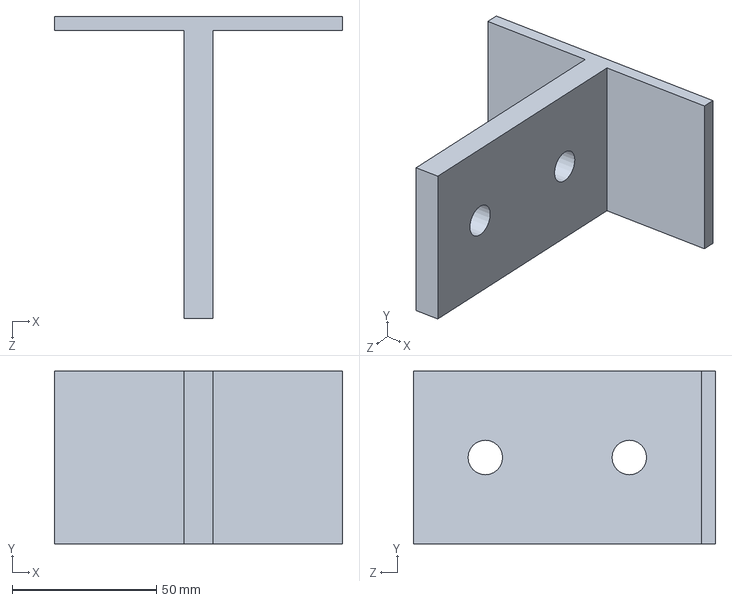
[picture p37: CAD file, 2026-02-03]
mecanica/Orejetas.SLDPRT
100.0 x 60.0 x 105.0 mm

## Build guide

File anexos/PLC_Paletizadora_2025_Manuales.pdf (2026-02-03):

CEMI Automatización | RDC

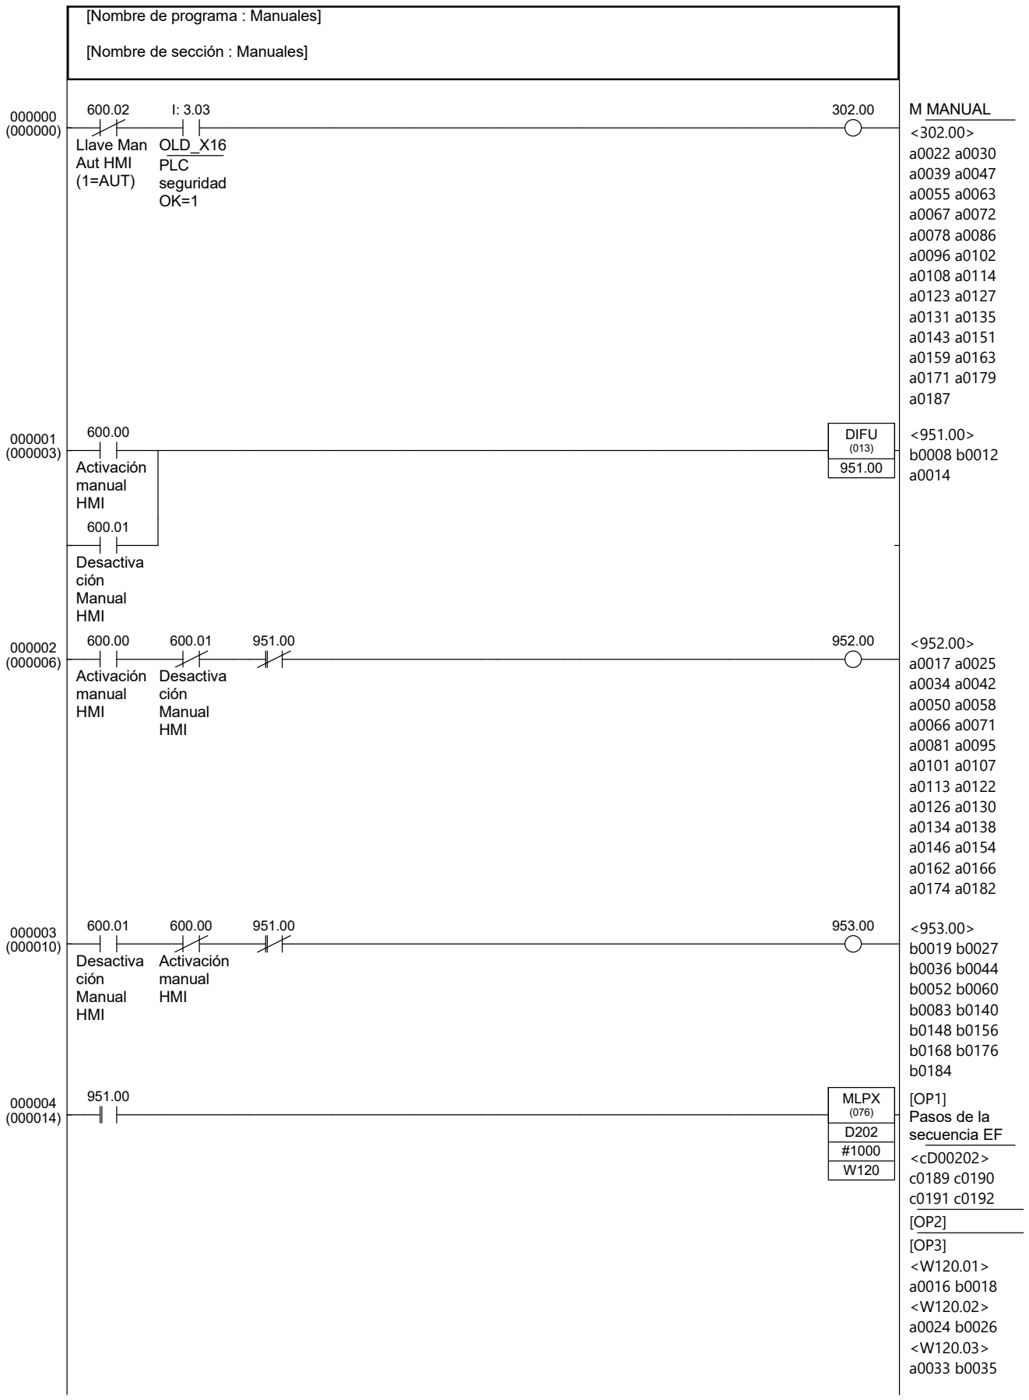
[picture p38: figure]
[Nombre de programa : Manuales]; [Nombre de sección : Manuales]; Llave Man Aut HMI; (1=AUT); OLD_X16 PLC seguridad OK=1; M MANUAL; Activación manual HMI; DIFU (013) 951.00; Desactiva ción Manual HMI; MLPX; [OP1] Pasos de la secuencia EF <cD00202> c0189 c0190 c0191 c0192 [OP2] [OP3] <W120.01> a0016 b0018 <W120.02> a0024 b0026 <W120.03> a0033 b0035

17/11/2025 | 1 / 8 | PLC_Paletizadora.cxp

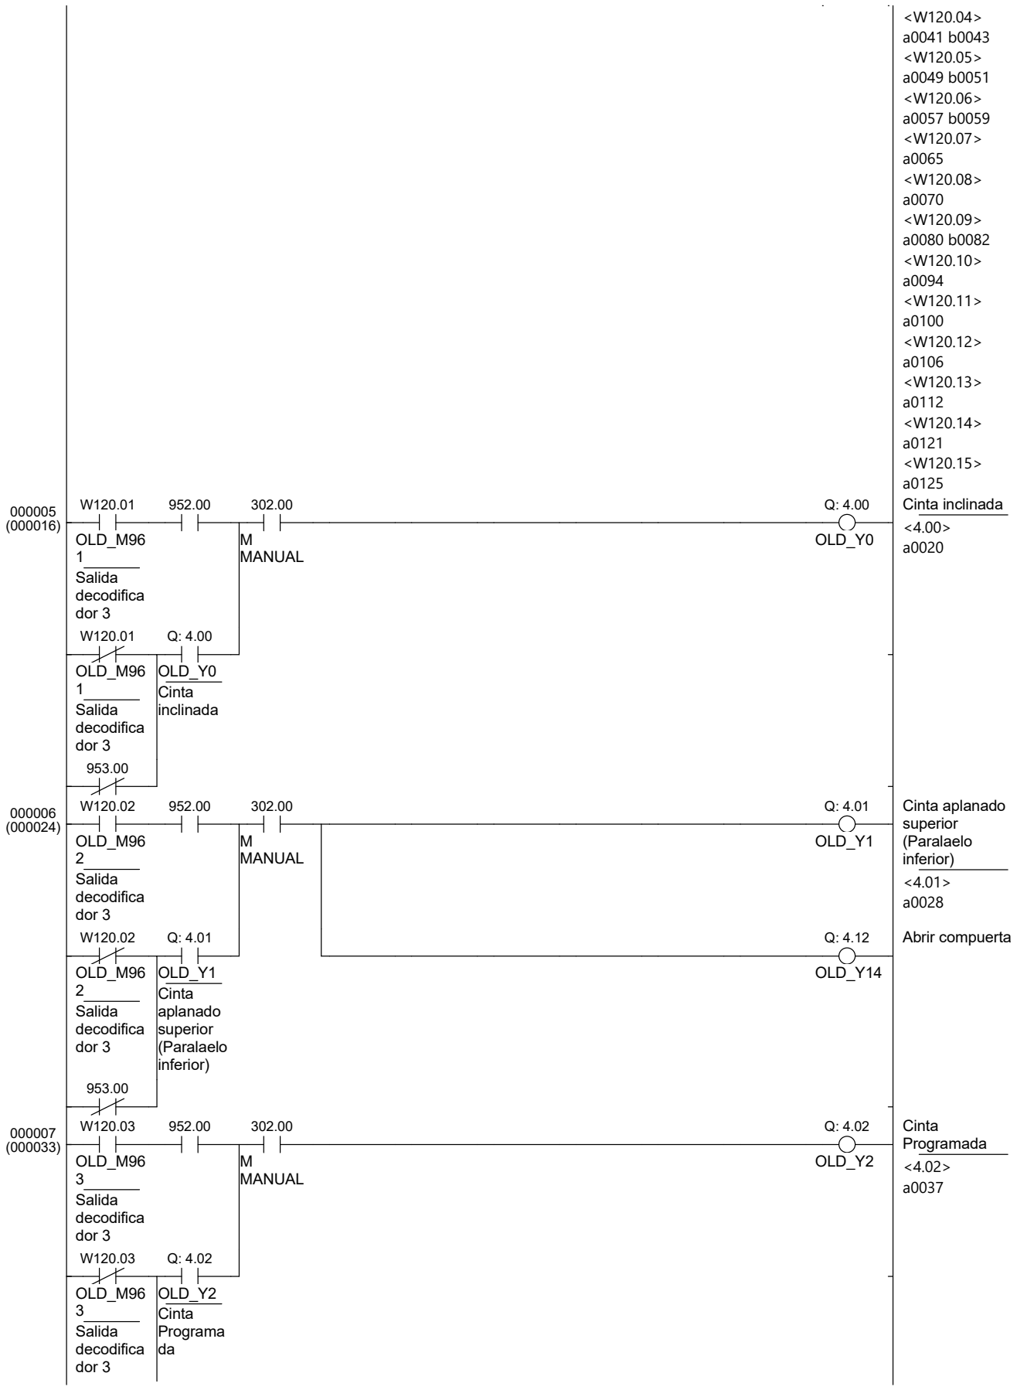
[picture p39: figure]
OLD_M96 1; Salida decodifica dor 3; M MANUAL; OLD_Y0; Cinta inclinada <4.00> a0020; OLD_Y0 Cinta inclinada; OLD_M96 2; OLD_Y1; Cinta aplanado superior (Paralaelo inferior) <4.01> a0028; OLD_Y1 Cinta aplanado superior (Paralaelo inferior); OLD_Y14; Abrir compuerta; OLD_M96 3; OLD_Y2; Cinta Programada <4.02> a0037; OLD_Y2 Cinta Programa da

17/11/2025 | 2 / 8 | PLC_Paletizadora.cxp

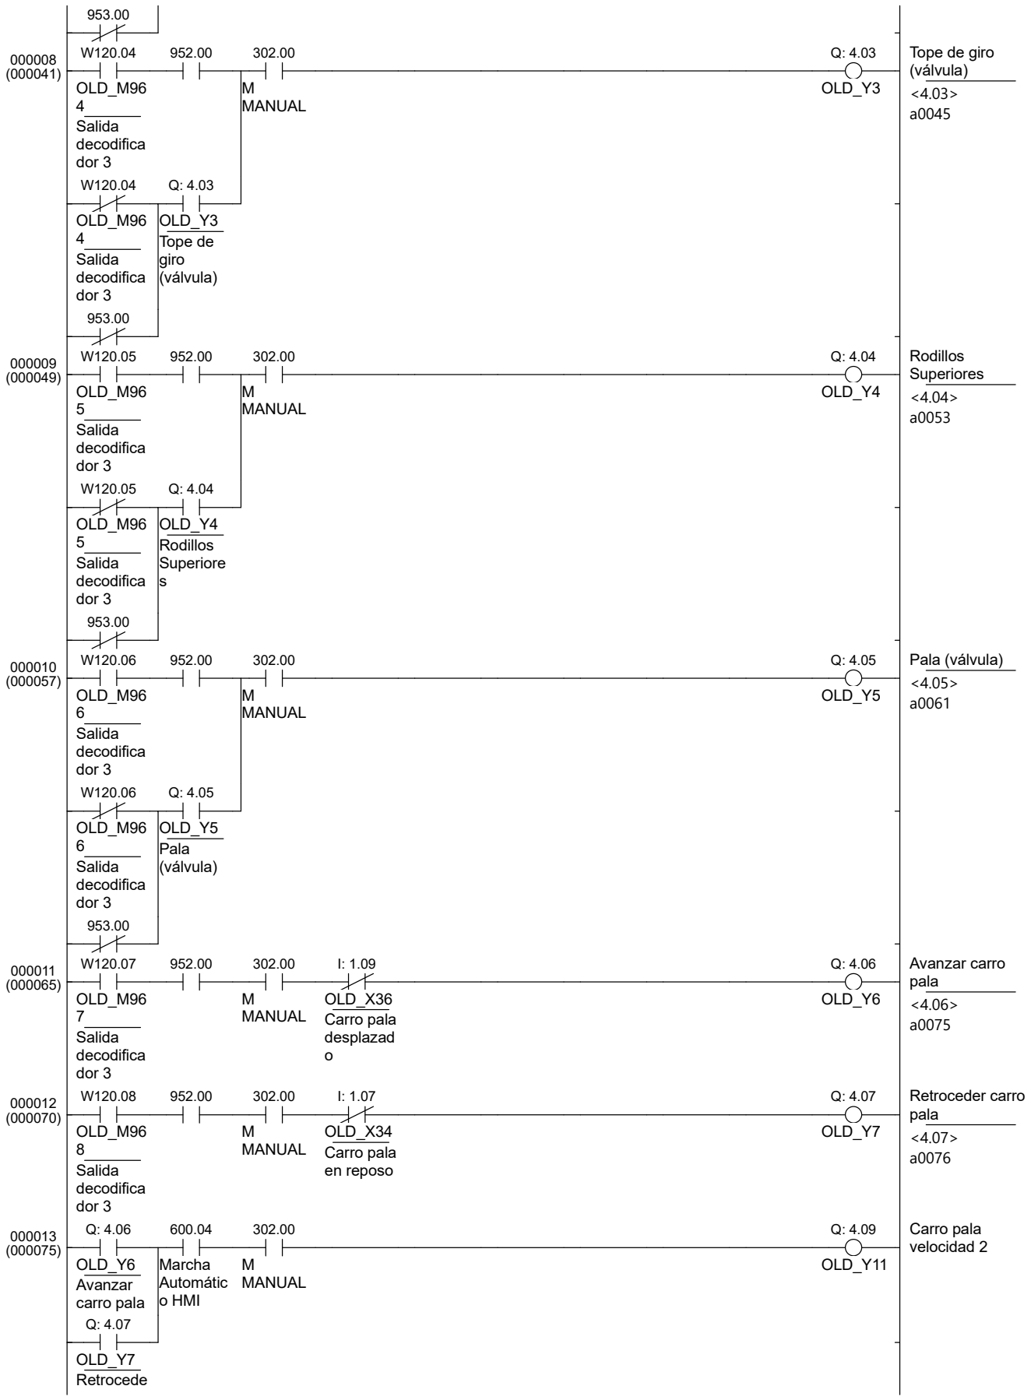
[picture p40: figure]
OLD_M96 4; Salida decodifica dor 3; M MANUAL; OLD_Y3; Tope de giro (válvula) <4.03> a0045; OLD_Y3 Tope de giro (válvula); OLD_M96 5; OLD_Y4; Rodillos Superiores <4.04> a0053; OLD_Y4 Rodillos Superiore s; OLD_M96 6; OLD_Y5; Pala (válvula) <4.05> a0061; OLD_Y5 Pala (válvula); OLD_M96 7; OLD_X36 Carro pala desplazad o; OLD_Y6; Avanzar carro pala <4.06> a0075; OLD_M96 8; OLD_X34 Carro pala en reposo; OLD_Y7; Retroceder carro pala <4.07> a0076; OLD_Y6 Avanzar; carro pala; Marcha Automátic; o HMI; OLD_Y11; Carro pala velocidad 2; OLD_Y7 Retrocede

17/11/2025 | 3 / 8 | PLC_Paletizadora.cxp

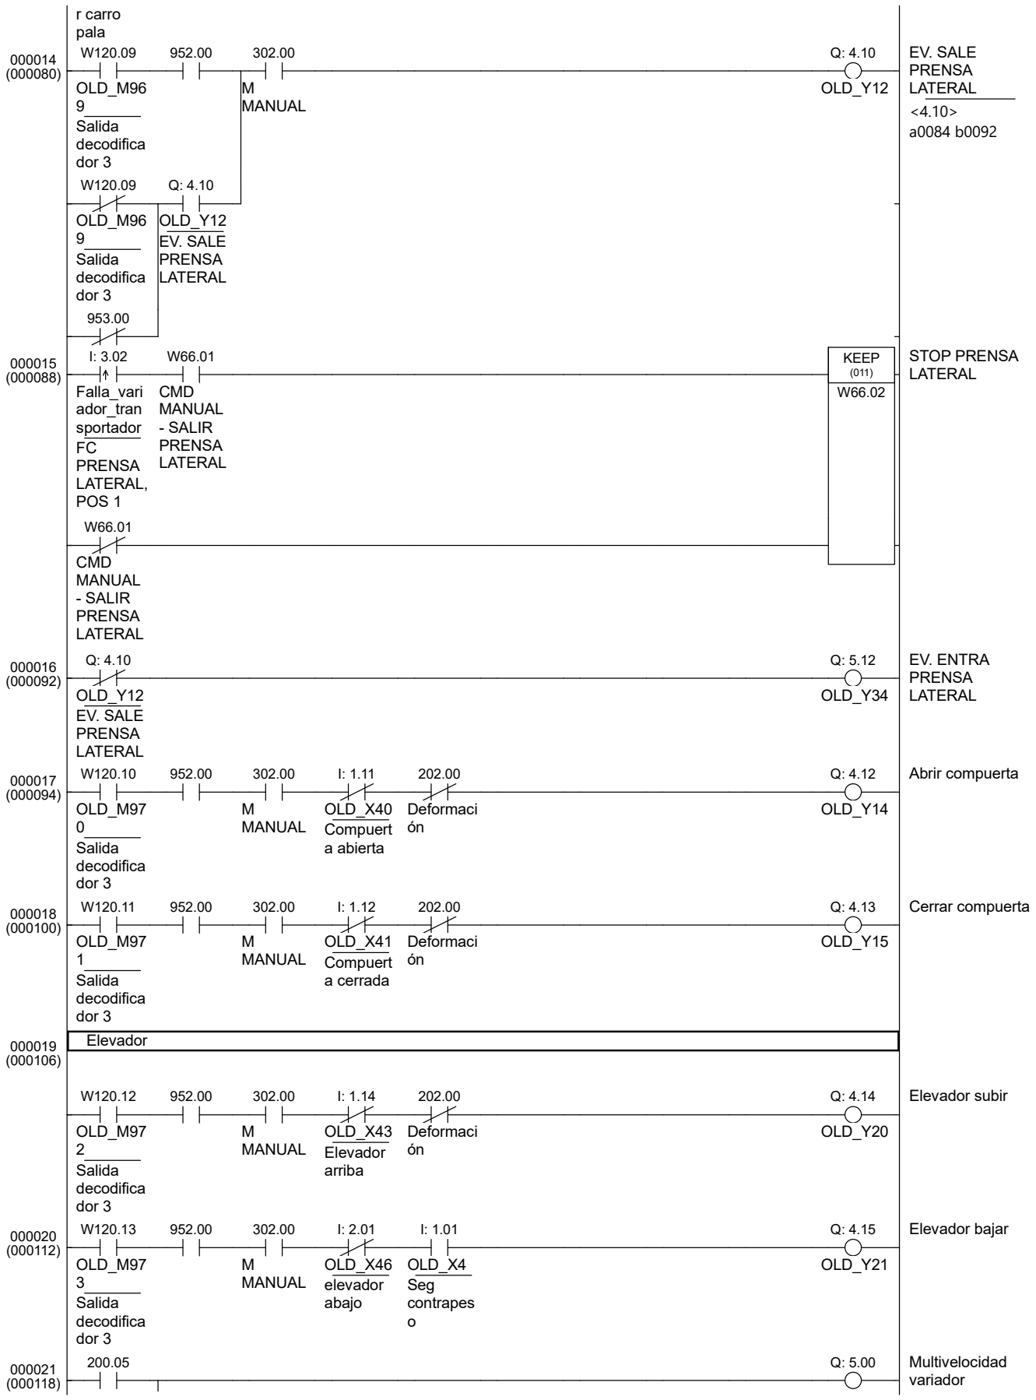
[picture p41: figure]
r carro pala; OLD_M96 9 Salida decodifica dor 3; M MANUAL; OLD_Y12; EV. SALE PRENSA LATERAL <4.10> a0084 b0092; OLD_Y12 EV. SALE PRENSA LATERAL; Falla_vari ador_tran sportador FC PRENSA LATERAL, POS 1; CMD MANUAL - SALIR PRENSA LATERAL; KEEP (011) W66.02; STOP PRENSA LATERAL; OLD_Y34; EV. ENTRA PRENSA LATERAL; OLD_M97 0 Salida decodifica dor 3; OLD_X40 Compuert a abierta; Deformaci ón; OLD_Y14; Abrir compuerta; OLD_M97 1 Salida decodifica dor 3; OLD_X41 Compuert a cerrada; OLD_Y15; Cerrar compuerta; Elevador; OLD_M97 2 Salida decodifica dor 3; OLD_X43 Elevador arriba; OLD_Y20; Elevador subir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

17/11/2025 | 4 / 8 | PLC_Paletizadora.cxp

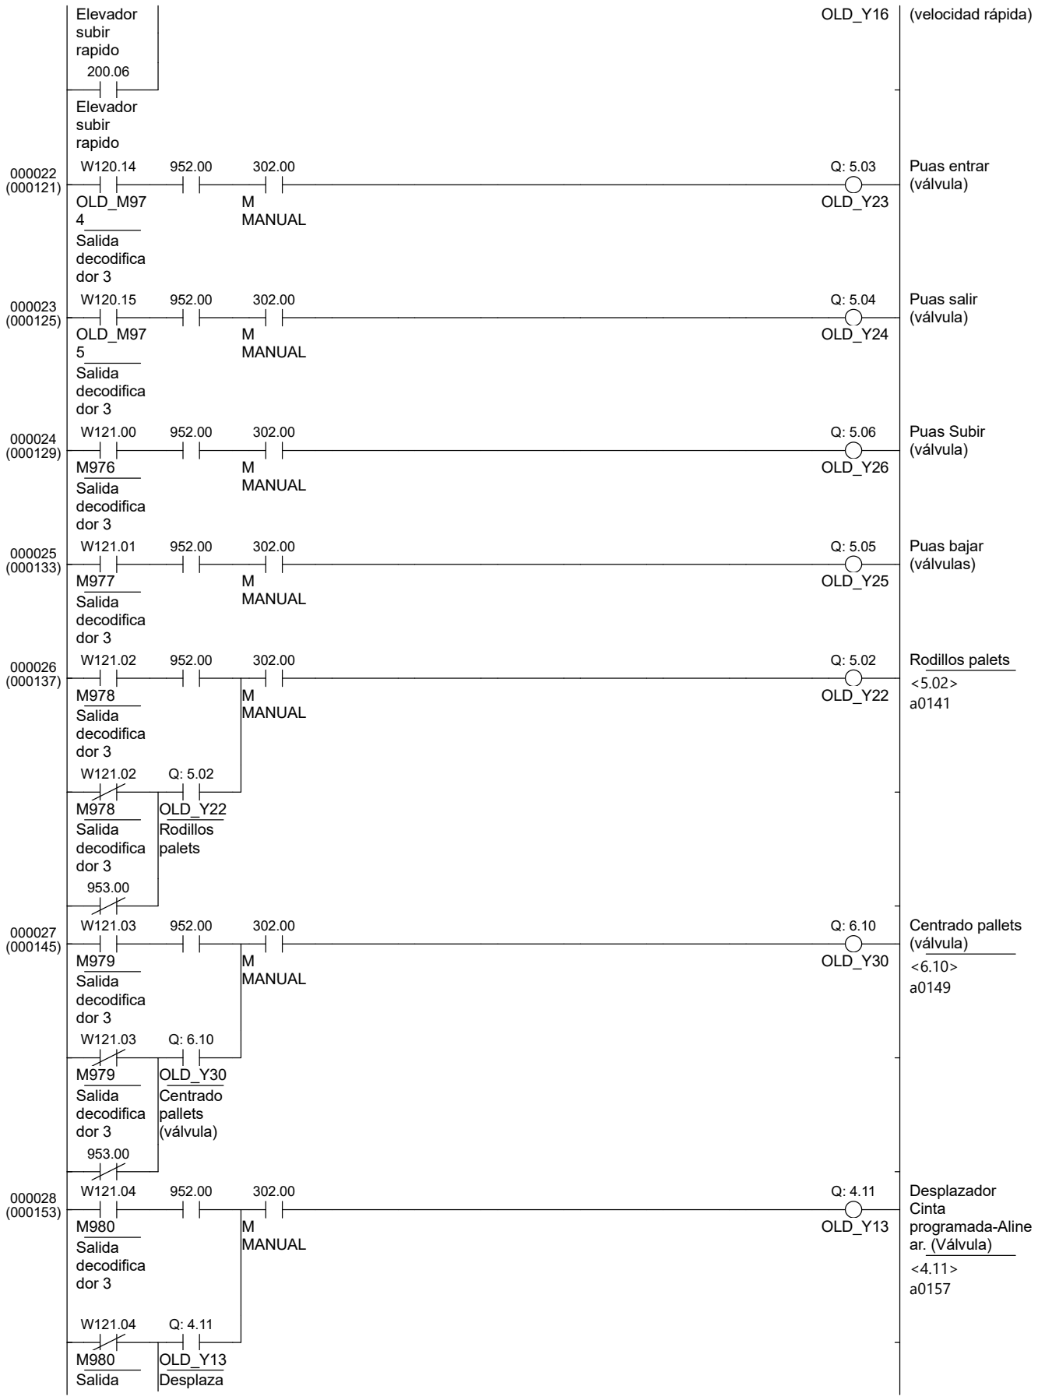
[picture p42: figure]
Elevador subir rapido; OLD_Y16; (velocidad rápida; OLD_M97 4; Salida decodifica dor 3; M MANUAL; OLD_Y23; Puas entrar (válvula); OLD_M97 5; OLD_Y24; Puas salir (válvula); M976 Salida decodifica dor 3; OLD_Y26; Puas Subir (válvula); M977 Salida decodifica dor 3; OLD_Y25; Puas bajar (válvulas); M978 Salida decodifica dor 3; OLD_Y22; Rodillos palets <5.02> a0141; OLD_Y22 Rodillos palets; M979 Salida decodifica dor 3; OLD_Y30; Centrado pallets (válvula) <6.10> a0149; OLD_Y30 Centrado pallets (válvula); M980 Salida decodifica dor 3; OLD_Y13; Desplazador Cinta programada-Alin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

17/11/2025 | 5 / 8 | PLC_Paletizadora.cxp

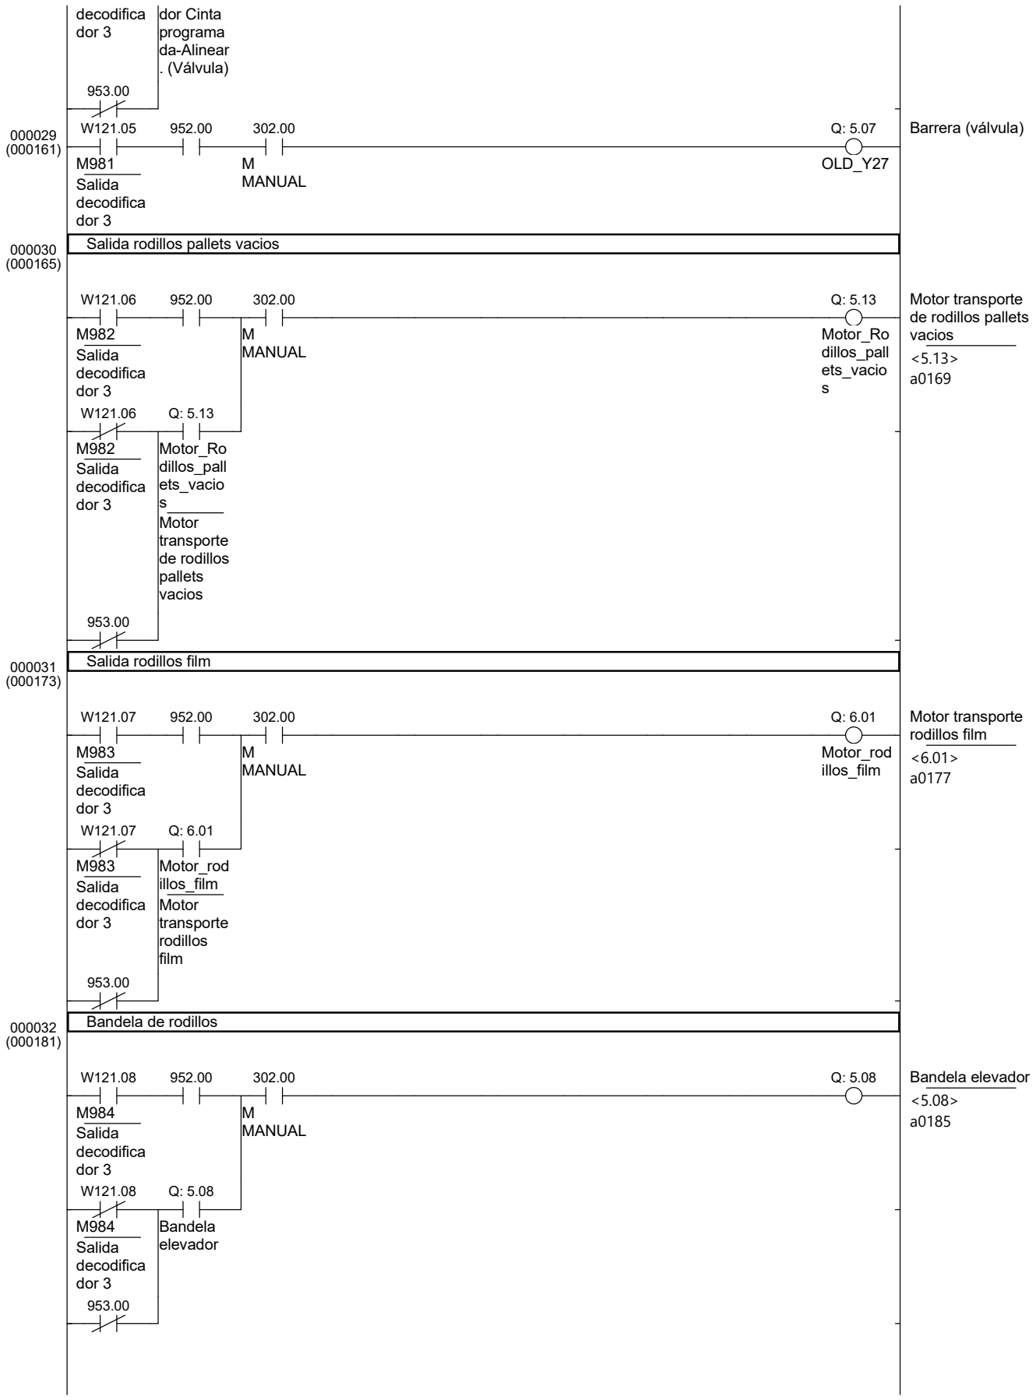
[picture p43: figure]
decodifica dor 3; dor Cinta programa da-Alinear . (Válvula); M981 Salida decodifica dor 3; M MANUAL; OLD_Y27; Barrera (válvula); Salida rodillos pallets vacios; M982 Salida decodifica dor 3; Motor_Ro dillos_pall ets_vacio s; Motor transporte de rodillos pallets vacios <5.13> a0169; Motor_Ro dillos_pall ets_vacio s Motor transporte de rodillos pallets vacios; Salida rodillos film; M983 Salida decodifica dor 3; Motor_rod illos_film; Motor transporte rodillos film <6.01> a0177; Motor_rod illos_film Motor transporte rodillos film; Bandela de rodillos; M984 Salida decodifica dor 3; Bandela elevador

17/11/2025 | 6 / 8 | PLC_Paletizadora.cxp

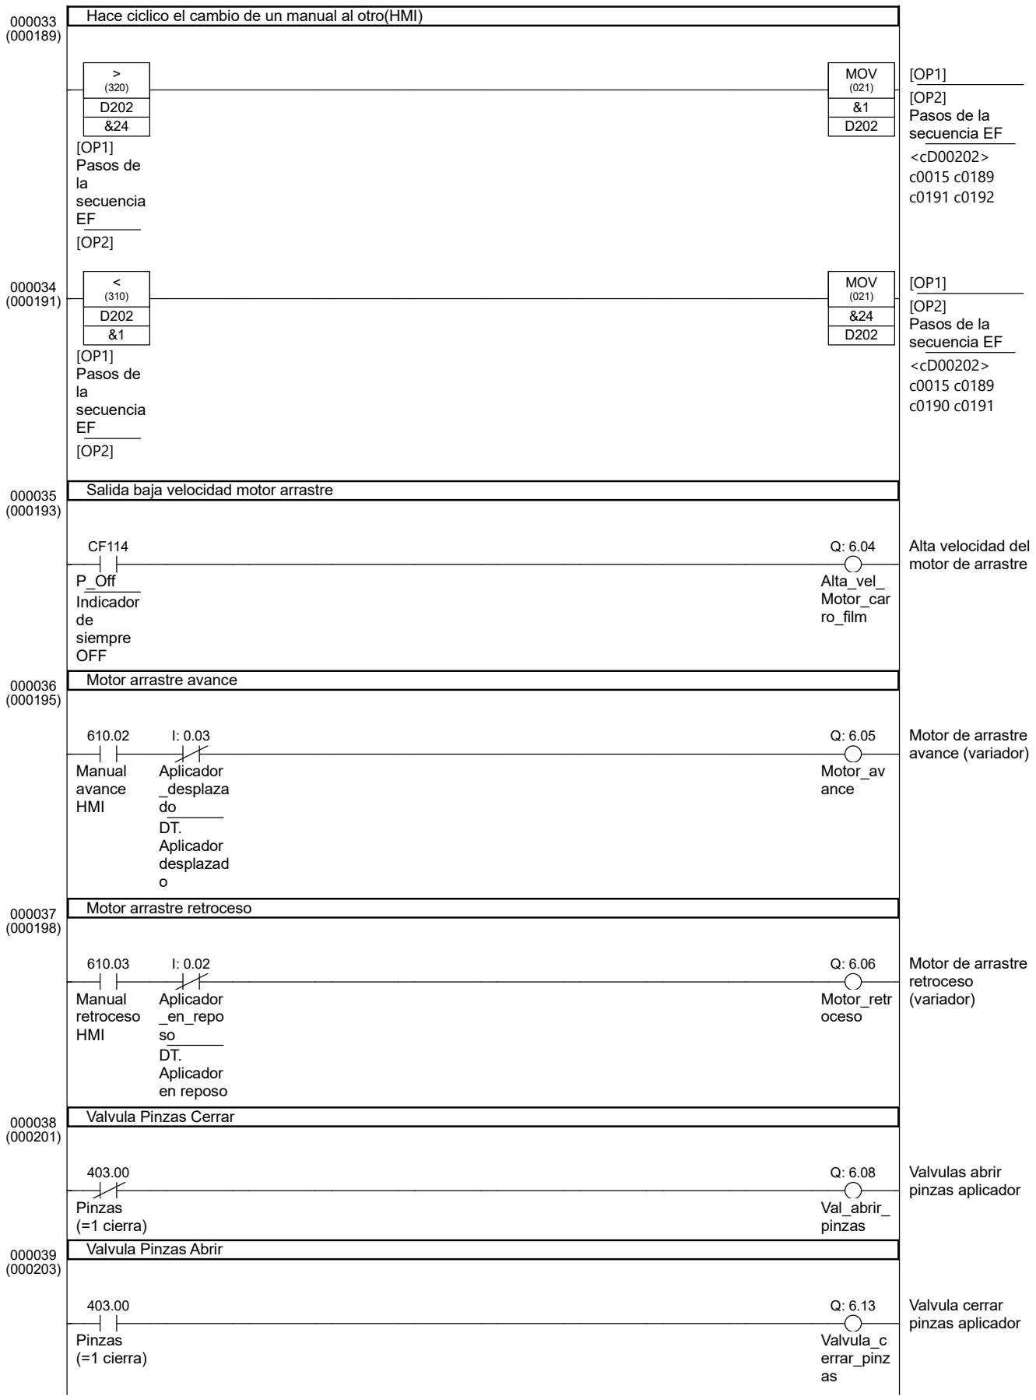
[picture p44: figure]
> (320) D202 &24 [OP1] Pasos de la secuencia EF [OP2]; MOV (021) &1 D202; [OP1] [OP2] Pasos de la secuencia EF <cD00202> c0015 c0189 c0191 c0192; < (310) D202 &1 [OP1] Pasos de la secuencia EF [OP2]; MOV (021) &24 D202; [OP1] [OP2] Pasos de la secuencia EF <cD00202> c0015 c0189 c0190 c0191; Salida baja velocidad motor arrastre; P_Off Indicador de siempre OFF; Alta_vel_ Motor_car ro_film; Alta velocidad del motor de arrastre; Motor arrastre avance; Manual avance HMI; Aplicador _desplaza do DT. Aplicador desplazad o; Motor_av ance; Motor de arrastre avance (variador); Motor arrastre retroceso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

17/11/2025 | 7 / 8 | PLC_Paletizadora.cxp

Hace ciclico el cambio de un manual al otro(HMI)

17/11/2025 | 8 / 8 | PLC_Paletizadora.cxp

000040
(000205)

Valvula corte

404.00

Corte
lamina

Q: 6.09

Val_corte

Valvula corte
lamina aplicador

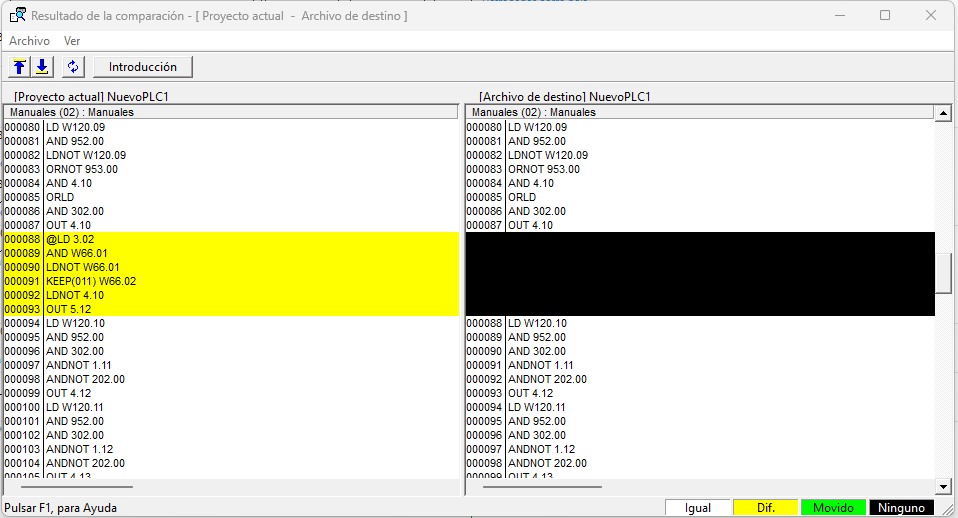
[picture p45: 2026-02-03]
imagenes/Diferencias_manuales.png

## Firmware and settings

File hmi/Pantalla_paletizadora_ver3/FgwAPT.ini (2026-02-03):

; (c) Copyright OMRON Corporation 1999
;	  All Rights Reserved
;     This file is used for NS
;======================================================
; 000609AM
; 000613AM
; 000707AM MMI/Y.Inoue
; 000731PM MMI/Y.Inoue
; 000809AM MMI/Y.Inoue
; 001017PM MMI/Y.Inoue
; 001102AM MMI/Y.Inoue
; 021227PM OSK/K.Ohnuki	MPRO
; 030418PM OSK/M.Yamamoto THERMO,MEMORY LINK
; 040202PM HMI/T.Ohtani $HB,$HW
; 040310AM HMI/T.Ohtani HSVM
; 040319AM HMI/T.Ohtani HLK(Fixed)
; 050421   HMI/Y.Sekigami Release for V6.5
; 060123   HMI/Y.Sekigami Release for V6.6
; 060615   HMI/D.TAKAHASHI Updated for NSH
; 061006   OSK/K.Ohnuki NT Compatible(add $SE)
;-------------------------------------------------------
; INI File Check
;-------------------------------------------------------
[iniCheck]
iniCheck=True
;-------------------------------------------------------
; SERVICES under SCM
;-------------------------------------------------------
[Services]
Services=RUT0,RUT1,CPU_UNIT,HSV0,HSV1,ETN
;-------------------------------------------------------
; PRIORITY & SCHEDULE
; Schedule=FIFO|RoundRobin|OTHER
;-------------------------------------------------------
[Priority]
CPU_UNIT=128
ETN=128
CLK=128
RUT0=512
RUT1=512
HLK0=1024
HLK1=1024
NTLK0=1024
NTLK1=1024
HSV0=1024
HSV1=1024
MPRO0=1024
MPRO1=1024
THERMO0=1024
THERMO1=1024
CWAYF0=1024
CWAYF1=1024
MEMLINK0=1024
MEMLINK1=1024
HSVM0=1024
HSVM1=1024
MVEN0=1024
MVEN1=1024
ENT_CIP=128
;-------------------------------------------------------
; FINS UNITID
;-------------------------------------------------------
[UnitID]
RUN=51
FINSAPT=53
CPU_UNIT=0
USB=19
ETN=17
CLK=18
RUT0=21
HLK0=31
HSV0=32
NTLK0=34
BCR0=42
MEMLINK0=43
MPRO0=44
THERMO0=45
CWAYF0=45
HSVM0=61
RUT1=25
HLK1=35
HSV1=36
NTLK1=39
BCR1=47
MEMLINK1=48
MPRO1=49
THERMO1=50
CWAYF1=50
HSVM1=62
MVEN0=31
MVEN1=35
[RouteTable]
RelayNetworks=
LocalNetworks=(1,17)(116,21)(117,25)
PassThroughUnit=
;-------------------------------------------------------
; CPU_UNIT
;-------------------------------------------------------
[CPU_UNIT]
StartType=auto
ImagePath=CPU_UNIT
CommandLine=CPU_UNIT
KillCommand=ScmControl -t -n CPU_UNIT<>>>/nil
HardwareType=
HardwareVersion=
RtcSetCommand=rtc -ls hw>/dev/null
;........................
; MEMORY ALIASES
;........................
MemoryAliases=$B,$W,$L,$TR,$HB,$HW,$A
$B=00
$W=02
$SB=04
$SW=06
$L=08
$TR=0A
$HB=0C
$HW=0E
$A=10
$SE=12
;-------------------------------------------------------
; EventMemory
;-------------------------------------------------------
;........................
; $B
;........................
[EmMemory_$B]
NumChannels=4096
NumConditions=0
AccessMethod=EmMemoryWOE
NeedMapMemory=TRUE
IsVolatile=TRUE
;........................
; $W
;........................
[EmMemory_$W]
NumChannels=65536
NumConditions=0
AccessMethod=EmMemoryWOE
NeedMapMemory=TRUE
IsVolatile=TRUE
;........................
; $SB
;........................
[EmMemory_$SB]
NumChannels=50
NumConditions=0
AccessMethod=EmFinsRemote
NeedMapMemory=FALSE
IsVolatile=FALSE
FinsAddress=0.0.0
TimeoutSecond=2
VariableType=00
VariableOffset=0000
NSJ=0
;........................
; $SW
;........................
[EmMemory_$SW]
NumChannels=100
NumConditions=0
AccessMethod=EmFinsRemote
NeedMapMemory=FALSE
IsVolatile=FALSE
FinsAddress=0.0.0
TimeoutSecond=2
VariableType=82
VariableOffset=0000
NSJ=0
;........................
; $L
;........................
[EmMemory_$L]
NumChannels=236544
NumConditions=0
AccessMethod=EmSRAMAccess
NeedMapMemory=FALSE
IsVolatile=FALSE
MemoryAddress=0x08000000
;........................
; $TR
;........................
[EmMemory_$TR]
NumChannels=2048
NumConditions=0
AccessMethod=EmMemoryWOE
NeedMapMemory=TRUE
IsVolatile=TRUE
;........................
; $HB
;........................
[EmMemory_$HB]
NumChannels=1024
NumConditions=0
AccessMethod=EmSRAMAccess
NeedMapMemory=FALSE
IsVolatile=FALSE
MemoryAddress=0x08073800
;........................
; $HW
;........................
[EmMemory_$HW]
NumChannels=16384
NumConditions=0
AccessMethod=EmSRAMAccess
NeedMapMemory=FALSE
IsVolatile=FALSE
MemoryAddress=0x08074000
;........................
; $A
;........................
[EmMemory_$A]
NumChannels=512
NumConditions=0
AccessMethod=EmSRAMAccess
NeedMapMemory=FALSE
IsVolatile=FALSE
MemoryAddress=0x0807C000
;........................
; $SE
;........................
[EmMemory_$SE]
NumChannels=100
NumConditions=0
AccessMethod=EmFinsRemote
NeedMapMemory=FALSE
IsVolatile=FALSE
FinsAddress=0.0.0
TimeoutSecond=2
VariableType=00
VariableOffset=0000
NSJ=0
;-------------------------------------------------------
; COM
;-------------------------------------------------------
[COM]
COMs=2
COM1=RUT0
COM2=RUT1
[COM1]
Device=/term
[COM2]
Device=/t1
;-------------------------------------------------------
; RUT
;-------------------------------------------------------
[RUT0]
ImagePath=RemoteUart
StartType=auto
CommandLine=RemoteUart -n 0
KillCommand=ScmControl -t -n RUT0<>>>/nil
SubProfile=FgwAPTRut.ini
[RUT1]
ImagePath=RemoteUart
StartType=auto
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

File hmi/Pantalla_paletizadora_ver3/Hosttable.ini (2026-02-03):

;=====================================================
; (c) Copyright OMRON Corporation 2004
;     All Rights Reserved
;=====================================================
; Hosttable.ini - ini file for NS-Designer Host Table
;-----------------------------------------------------
;-----------------------------------------------------
; INI File Check
;-----------------------------------------------------
[iniCheck]
iniCheck=True
;-----------------------------------------------------
; The No. of Hosts
;-----------------------------------------------------
[Hosts]
Hosts=4
;-----------------------------------------------------
; Host Tables
;-----------------------------------------------------
[HOST1]
HostName=PTMEM
HostNumber=0
TimeOut=3000
RetryCnt=5
AutoRevert=0
MessageInterval=20
HostType=0
ExclusiveControl=0
Protocol=0
NetAddr=0
NodeAddr=0
UnitAddr=0
0101Max=511
0102Max=511
0104Max=511
2301Max=63
0111Max=0
TransMax=32
TransCycle=1

[HOST2]
HostName=SerialA
HostNumber=1
TimeOut=3000
RetryCnt=5
AutoRevert=0
MessageInterval=20
HostType=1
ExclusiveControl=1
Protocol=-1
NetAddr=111
NodeAddr=1
UnitAddr=0
0101Max=127
0102Max=126
0104Max=127
2301Max=63
0111Max=127
TransMax=32
TransCycle=1

[HOST3]
HostName=SerialB
HostNumber=2
TimeOut=3000
RetryCnt=5
AutoRevert=0
MessageInterval=20
HostType=1
ExclusiveControl=1
Protocol=-1
NetAddr=112
NodeAddr=1
UnitAddr=0
0101Max=127
0102Max=126
0104Max=127
2301Max=63
0111Max=127
TransMax=32
TransCycle=1
[HOST4]
TimeOut=3000
RetryCnt=5
AutoRevert=0
MessageInterval=20
HostName=HOST3
NetAddr=1
NodeAddr=26
UnitAddr=0
HostNumber=3
ExclusiveControl=0
HostType=31
Protocol=3
0101Max=256
0102Max=256
0104Max=256
2301Max=63
0111Max=0
0101BitMax=-1
0102BitMax=-1
CIP_Max=0
CIPMessageType=0
TransMax=32
TransCycle=1
